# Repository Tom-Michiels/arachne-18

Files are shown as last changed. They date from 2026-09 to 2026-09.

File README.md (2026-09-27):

<div align="center">

# ARACHNE / 18 — v4

**Six legs. Eighteen servos. Three monolithic moving links per leg.**

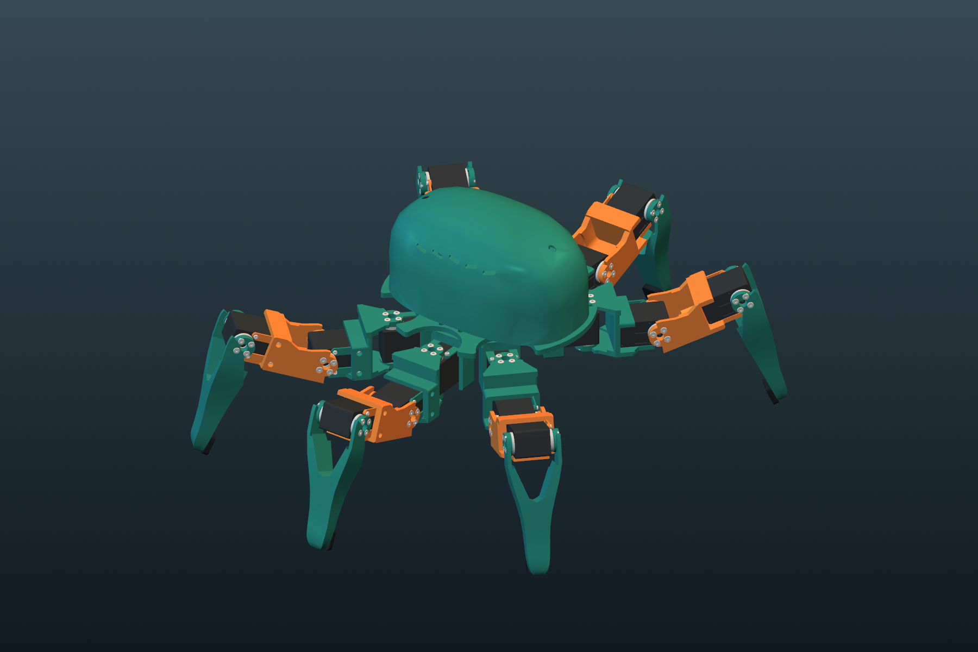
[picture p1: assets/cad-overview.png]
The complete v4 robot, rendered from its actual CAD


**18 × STS3215 12 V** · **3D printable** · **Onshape** · **MuJoCo + BAM**

[Onshape assembly](https://cad.onshape.com/documents/88edbeda4232642329938c14/w/19f5435855c2974f02fa7c68/e/916e6d95108202647e946643) · [Download print pack](print/ARACHNE_18_v4_print_pack.zip) · [Build guide](docs/build-guide.md) · [Simulation setup](docs/another-computer.md)

</div>

ARACHNE 18 is a compact six-legged prototype built around the owner's eighteen Feetech STS3215 12 V servos. This revision integrates the v4 leg and chassis into the complete robot: a single printed chassis, six identical leg modules, a removable controller carrier, and an organic ventilated canopy.

Each moving link is one printed piece. The tibia is symmetric, the horn cheeks have equal spacing, and the case cradles use the servo's factory mounting points. Local openings on the dummy side provide connector access. Horns sit inside the forks; recessed DIN 7380 button-head screws sit outside. There are no loose structural shims.

| Specification | v4 |
|---|---|
| Mechanism | Six yaw–hip–knee chains; 18 revolute joints |
| Chassis | 194 × 173.5 × 56 mm; six mounts on an 86 mm radius |
| Link geometry | Coxa 62 mm; hip offset −6.95 mm; femur 78 mm |
| Measured horn span | 36.5 mm; driven horn 2.5 mm, dummy horn 2.0 mm |
| Forks | 36.9 mm internal span; 5.5 mm cheeks; Ø7.3 mm center access |
| Battery envelope | 115 × 40 × 35 mm, excluding protruding plugs |
| Controller envelope | 90 × 60 × 18 mm; configurable 64 × 48 mm hole pattern |
| Printed parts | 8 unique files; 31 pieces including 6 TPU shoes and 4 PCB standoffs |
| Modelled hardware | 160 DIN 7380 M3 screws, 72 supplied PA2 case screws, 16 M3 inserts, 36 horns |
| Simulation | 19 rigid links, 18 actuators, 336 visual parts; estimated mass 2.333 kg |

## Inside the robot

| Removable electronics carrier | Symmetric six-leg layout |
|---|---|
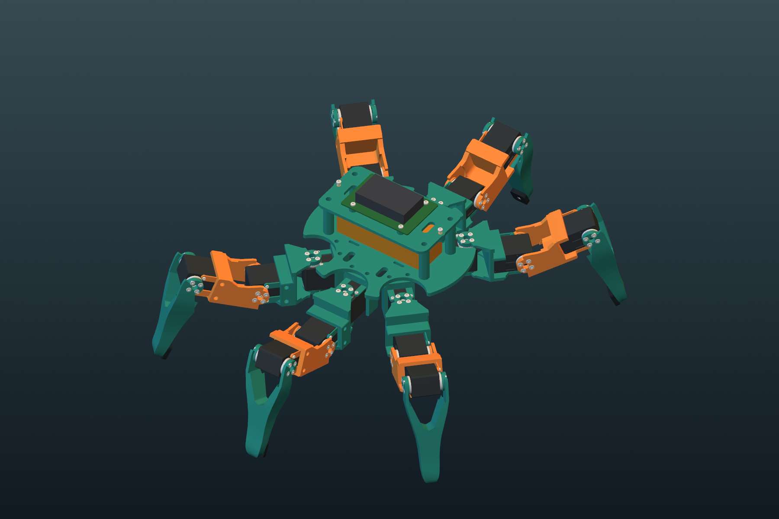
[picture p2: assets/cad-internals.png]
Actual v4 CAD with canopy removed
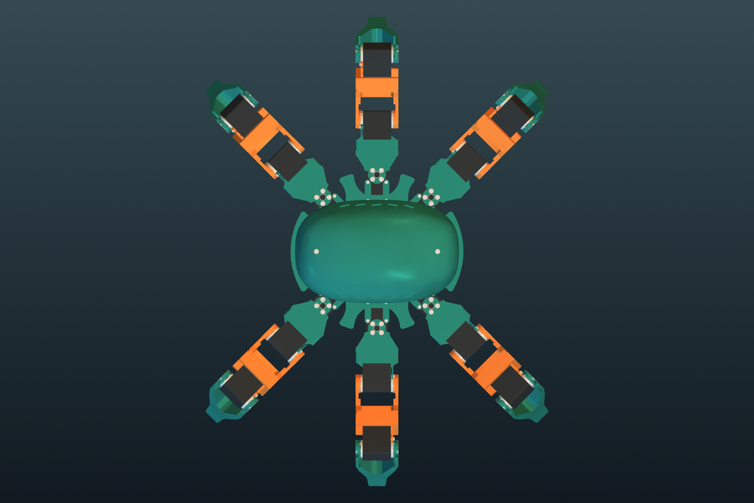
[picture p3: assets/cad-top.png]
Actual v4 CAD, top view
|  |  |

The battery rests on the chassis and is retained by two straps. Four integrated posts support the controller carrier. Its mounting screws are reached through deep open wells. Two recessed M3 screws hold the canopy; straight tool openings make them accessible from above. Four small standoffs provide a 6 mm PCB air gap.

The front and rear pairs can touch their toes through a checked coordinated pose: inward yaw approximately 57.51°, hip −20°, knee 0°. This is a reach pose, not a walking command. Independent joint limits do not guarantee arbitrary combinations are collision-free.

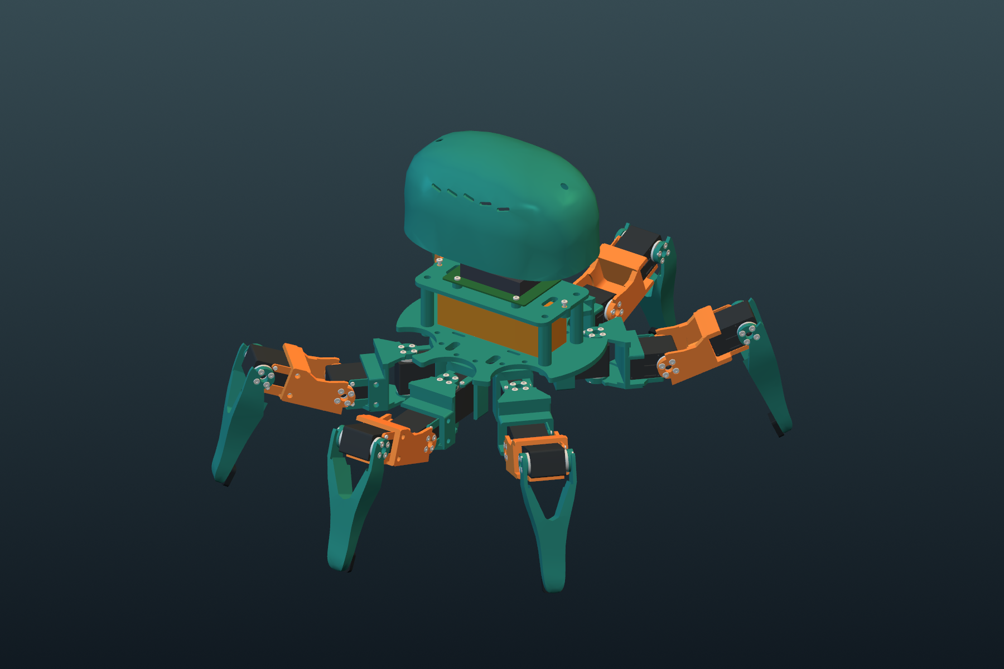
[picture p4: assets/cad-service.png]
V4 service view


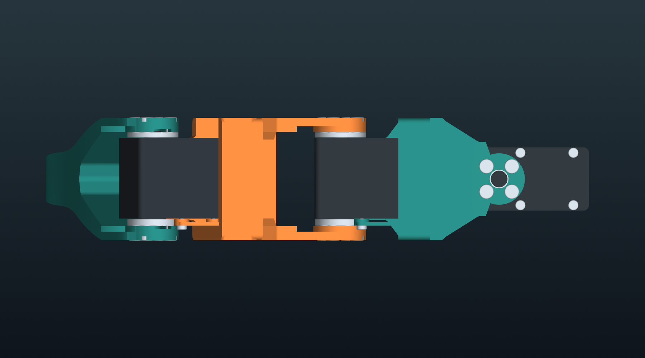
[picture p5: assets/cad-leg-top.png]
Top view of one v4 leg, with equal fork spacing


## Print and assemble

Download the [STL bundle](print/ARACHNE_18_v4_print_pack.zip), [assembled STEP](cad/ARACHNE_18_assembly.step), or [individual STEP parts](cad/parts). STL units are millimetres; use 100% scale and the supplied orientations. All parts fit the H2D.

Start with one complete leg and a real servo. The [build guide](docs/build-guide.md) explains mounting order, screw lengths, insert positions, connector clearance and support removal. M3 plastic-thread joints use **Ruthex RX-M3x5.7**, with **Ø4.0 × 7 mm pilots**. Horn screws thread into metal horns; supplied case screws thread into the servo's factory mounting points.

The structural pieces have continuous flat bed faces. The curved canopy needs internal support; support is also needed locally beneath some fork bridges. All eight parts were sliced successfully with an A1 geometry proxy profile. **Reslice for your H2D**; no machine-ready G-code is supplied.

## Run MuJoCo

From a fresh clone, with Python 3.12:

```sh
git clone https://github.com/Tom-Michiels/arachne-18.git
cd arachne-18
python3.12 -m venv .venv
source .venv/bin/activate
python -m pip install -r simulation/requirements.txt
python simulation/simulate.py --headless --seconds 10 --voltage 11.1
python simulation/validate.py
```

For an interactive viewer on macOS:

```sh
mjpython simulation/grounded_demo.py --seconds 300
```

Use `python` for the viewer on Linux/Windows. On Windows activate with `.venv\Scripts\activate`. See [setup on another computer](docs/another-computer.md) and the [simulation guide](docs/simulation.md).

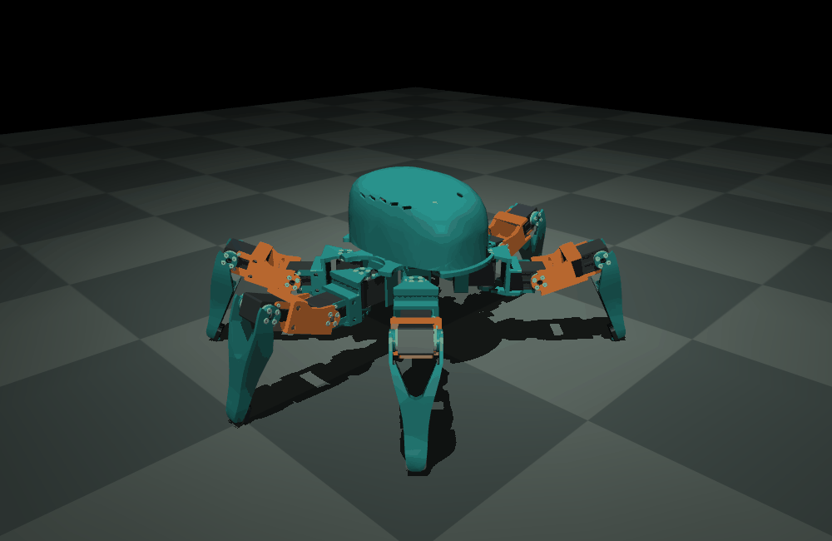
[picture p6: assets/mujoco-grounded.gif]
Actual v4 floating-base MuJoCo body-height exercise


The animation is a BAM-driven body-height exercise. All six feet remain in contact; the base is free. The 12 V actuator parameters are an explicitly labelled approximation derived from BAM's identified 7.4 V model and manufacturer operating points. [BAM assumptions](docs/bam-model.md).

## Existing RL work

**No RL retraining was performed for v4.** Existing checkpoints, measurements and walking/jump/terrain videos are preserved. They were produced with earlier geometry and do not establish v4 performance. The training model and inverse kinematics now use v4 dimensions; controller and geometry compatibility tests are included.

[Training documentation](training/README.md) · [Archived locomotion videos](https://tom-michiels.github.io/arachne-18/) · [Revision notes](docs/revision-v4.md)

## Validation and limitations

Eight valid single-solid print parts and eight watertight single-component STLs pass the current checks. The release includes screw/print clearance checks, driver access checks, the isolated leg's factory-hole and connector tests, chassis installation tests, sampled dorsal motion and paired-toe reach evidence. MuJoCo passes topology, joint axes, standing at three voltages, reset reproducibility and grounded motion checks. [Scope and reports](docs/validation.md).

This is a digitally checked prototype. Real servo/horn/plug fit, print tolerances, insert pull-out strength, fatigue and payload capacity need a physical one-leg trial. The controller and battery are envelopes because exact models have not been specified. Servo visuals are simplified exterior references; the original vendor STEP is retained for mechanical checks.

## Files and sources

| Folder | Contents |
|---|---|
| [cad](cad) | Assembly, unique-part layout, individual STEP solids, dimensions and reference geometry |
| [print](print) | Oriented STLs, print quantities and downloadable print pack |
| [simulation](simulation) | MJCF, local-frame meshes, BAM parameters, runtime and validation |
| [src](src) | Parametric CadQuery source, exporters, CAD checks and Onshape mate tooling |
| [docs](docs) | English build, simulation, validation and development guides |
| [training](training) | Updated model adapter and preserved historical RL work |

Actuator modelling uses [Rhoban/BAM](https://github.com/Rhoban/bam); simulation uses [MuJoCo](https://github.com/google-deepmind/mujoco). See [third-party notices](THIRD_PARTY_NOTICES.md). No project-wide open-source license has been selected; bundled BAM material retains its Apache-2.0 license.

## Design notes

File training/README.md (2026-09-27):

# Smooth, IMU-aware locomotion

> **Mechanical revision v4:** checkpoints, recorded metrics and videos below are historical pre-v4 results. No RL retraining was performed. Current model/IK adapters use v4 geometry; prior performance is not established for v4. See [revision notes](../docs/revision-v4.md).

**Latest:** [faster walking with longer strides](LONG_STRIDE.md), including
a 44-second video and 26/26 reference checks. The new forward gait reaches
22.4 cm/s with 43% greater foot excursion than the original solo gait.
The [uneven-ground curriculum](TERRAIN.md) has passed admission through
4 mm obstacles and stops before the unmastered 8 mm stage.

ARACHNE now has a learned command-conditioned walking policy, independent BAM
validation, and real physics recordings. Start with
[`policies/omni.json`](policies/omni.json): it walks forward, backward, sideways,
diagonally, turns both ways, combines translation and rotation, and stops.

This is **episodic reward-based policy search using the cross-entropy method
(CEM)** over a 12-parameter controller. It is not a trained neural network or
PPO. The tripod pattern and inverse kinematics are explicit priors; training
learns cadence, stance fraction, foot clearance, stride/yaw/lateral gains,
body height, stance radius, IMU feedback strength, and phase corrections.

## Recorded results before the symmetric-leg revision

These archived verification figures used the original collision proxies and
the complete BAM M6 runtime at a 1 ms physics step. The symmetric-leg CAD
revision subsequently updated `simulation/arachne.xml`. Gait, terrain and jump
unit tests pass with the revised model, and the general walking policy passed
a five-second BAM smoke run; the full performance table below has not yet been
remeasured on that geometry. Training used a separate approximate model.

| Case | Measured motion | Body tilt RMS | Height variation, standard deviation |
|---|---:|---:|---:|
| General policy, 14 cm/s forward command | 13.29 cm/s | 0.060° | 0.395 mm |
| General policy, 20 cm/s forward command | 19.3 cm/s | 0.064° | See validation JSON |
| Fast policy, 20 cm/s forward command | 18.98 cm/s | 0.068° | 0.431 mm |
| Continuous 40-second direction/turn/stop demo | Multiple commands | 0.084° | 0.376 mm |

The fast policy trades a small amount of speed for less foot slip: 2.36 cm/s
RMS versus approximately 3.7 cm/s for the general policy at the 20 cm/s command.
Use the general policy for arbitrary directions; the fast policy was optimized
and verified for forward motion only.

**26/26 held-out/reference checks passed**, including 16 directions (eight
intermediate directions were not in the training command set), both yaw signs,
a combined command, slow/fast movement, standing, friction 0.5/1.1, a 200 g
payload, and 0.25° orientation-estimate noise with 0.005 rad/s gyro noise. Each
case lasts 12 seconds. The 40-second continuous demo has no falls, no non-foot
ground contacts, no solver warnings, and a maximum tilt of 0.297°.

Reports: [`results/validation.json`](results/validation.json),
[`results/fast_bam.json`](results/fast_bam.json),
[`../assets/arachne-learned-omni.json`](../assets/arachne-learned-omni.json).
These are simulation results, with the repository's provisional 12 V BAM
approximation. A separate [uneven-ground curriculum](TERRAIN.md) now has bounded
simulation checks. Hardware, impacts, thermal limits and measured actuator
parameters have not been validated by this work.

## Why the movement is smooth

- Alternating support tripods have coordinated phases. The stance/swing
  horizontal paths join with continuous position, velocity and acceleration;
  the `sin^4` foot lift also has zero velocity and acceleration at touchdown.
- A five-degree polynomial ramps motion in; a 250 ms command filter blends
  changes of direction. Cadence and foot clearance decrease at lower speeds.
- Joint targets pass through a low-pass filter and a 4.717 rad/s slew limit,
  then stay inside the original ±20° yaw and ±15° hip/knee limits.
- IMU projected gravity controls body tilt. A short prediction using body-frame
  gyro adds damping. The controller never observes global position, absolute
  heading or simulator ground-truth linear velocity. Ground-truth velocity is
  used only by the training reward and evaluation metrics.

The original policy uses this running reward:

```text
+ 5.0 exp(-||v_xy - command_xy||² / 0.0016)
+ 1.5 exp(-(yaw_rate - command_yaw)² / 0.09)
- 90 tilt_xy²
- 20 ||roll_pitch_rate||²
- 80 vertical_velocity²
- 400 (body_height - 0.095)²
- 15 stance_foot_slip²
- 0.025 mean(target_rate²)
- 0.00015 mean(target_acceleration²)
- 0.025 mean(motor_torque²)
- 30 for a fall, excessive tilt/height or non-finite state
```

Search maximizes average return after a 1.5 s settling period. Omnidirectional
selection uses 70% mean command return plus 30% worst command return. The top
eighth of the population updates the sampling distribution, with variance
floors and a retained incumbent. There is no bonus for arbitrary speed, so
overshooting or standing still cannot replace command tracking.

The newer longer-stride experiment adds measured progress per cycle (capped
at 0.12 m), stronger slip penalties, and a target-jerk penalty. Its exact
weights and run configuration are stored alongside the results. The original
policy and its validation report remain available for comparison.

## Run the trained controller or render the videos

Python 3.12, from the repository root, in a separate environment:

```sh
python3.12 -m venv .venv-walk
source .venv-walk/bin/activate
python -m pip install -r training/requirements.txt
python training/test_gait.py
python training/evaluate.py --policy training/policies/omni.json --command .14 0 0
python training/validate_policy.py --policy training/policies/omni.json
python training/render_demo.py --policy training/policies/omni.json
python training/evaluate.py --policy training/policies/fast.json --command .20 0 0 --seconds 12
python training/render_army.py --run training/recordings/army
```

Evaluation, tests, and rendering need standard MuJoCo and BAM; they do not need
the custom Metal physics library. The HUD is telemetry over a real simulation
capture. macOS rendering needs a graphics-capable session.

## Train with the fast local simulator

Training requires the **fused** `_mjmlx_native` build of MuJoCo-MLX-Cpp. This run
used the existing local `metal-opt` branch, commit
`4d84f84871f59378fa9f5636cf40efe16ed3f321`, on an Apple M4 Max. At publication time
that local fused implementation is not on the public upstream `main` branch;
cloning public main alone does not provide this training backend. The scripts
check support and fail explicitly if the necessary fused API/model support is
missing. Point `PYTHONPATH` to the local build with a matching Python/MLX ABI.

```sh
export PYTHONPATH=/path/to/MuJoCo-MLX-Cpp/build
python training/build_model.py
python training/check_metal.py

# First train and independently verify forward walking.
python training/metal_search.py --population 256 --generations 30 --speed .14 --out training/runs/forward
python training/evaluate.py --policy training/runs/forward/policy.json --command .14 0 0

# Then train eight directions, turns, a curve, and standing together.
python training/metal_search.py --stage omni --population 128 --generations 30 --speed .14 \
  --resume training/runs/forward/policy.json --out training/runs/omni
python training/validate_policy.py --policy training/runs/omni/policy.json

# Optional faster forward policy, preserving the smoothness objective.
python training/metal_search.py --population 256 --generations 25 --speed .20 \
  --resume training/runs/omni/policy.json --out training/runs/fast

# Record genuine population rollouts for the army video.
python training/metal_search.py --population 128 --generations 16 --seconds 8 --speed .14 \
  --capture-generations 0 5 15 --out training/runs/army
python training/render_army.py --run training/runs/army
```

The published weights came from an initial forward exploration, a second
forward smoothness pass, then the omni and fast stages. The current commands
use the final reward from the beginning and retrain a new run, not a bitwise
reproduction of the earlier exploration. Seeds, generation counts, returns,
timings and controller hash are in
[`results/training_summary.json`](results/training_summary.json).

The omni stage evaluated 1,536 environments per generation. It completed
27.648 million control steps / 138.24 million physics substeps in approximately
132 seconds, including logging and local background work. This is an observed
run timing, not an isolated benchmark.

## Model approximation and validation boundaries

`build_model.py` preserves CAD inertias, kinematics, mass and joint limits.
For the fused solver it uses Euler at 2 ms, pyramidal friction, 26-vertex foot
hulls and a torso hull. Training excludes self-collision and uses static
BAM-derived proportional gains, rotor inertia, damping/back-EMF and Coulomb
friction. It includes the external target filter, slew limit and 10 ms target
delay; the original reference adds BAM's approximately 5 ms command delay and
dynamic load-dependent friction. Foot slip during training uses a height-based
contact estimate; reference reports use actual ground contacts.

The independent 32-environment, five-substep comparison against MuJoCo C on the
same approximate model gave maximum errors of `9.04e-8` in qpos and `2.51e-6`
in qvel. This tests the backend for those states; it does not make the approximate
model identical to the full BAM model. Final policy validation and all solo
video physics use the original model and complete BAM runtime.

## Training-army provenance

The army video shows **128 independent candidates**, not copies of one trained
animation. The three clips replay actual qpos tensors recorded during
generations 0, 5 and 15 of a new training run (displayed as generations 1, 6 and
16). Original structural CAD meshes are positioned from those tensors in a
MuJoCo renderer. Small hardware is omitted in the distant overview.

Grid placement is a display offset: the training worlds do not collide with
one another. Gold shells mark the elite candidates selected from the completed
generation. Playback is at simulation time; the title does not claim rendering
ran live at training speed. Raw recordings include candidate parameters,
commands, rewards and metrics in [`recordings/army/`](recordings/army/), with
SHA-256 hashes in the [video manifest](../assets/arachne-training-army.json).

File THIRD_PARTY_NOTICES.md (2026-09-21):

# Sources and third-party notices

## Better Actuator Models

[BAM](https://github.com/Rhoban/bam) is developed by Rhoban and distributed under Apache-2.0. This repository includes an original STS3215 7.4 V M6 parameter snapshot and a modified 12 V approximation. The modification fits effective torque/speed coefficients to Feetech's 12 V datasheet; it is not an upstream identified 12 V model. See [the model notes](docs/bam-model.md) and the [included license](licenses/BAM_APACHE_2.0.txt).

Upstream parameter snapshot: `e9a619d56da5236206f4de6ceec2c1ee1b497b5c`. Installed runtime: `better-actuator-models==1.0.2` from PyPI.

## Mechanical and electrical references

- [Feetech ST-3215-C018 12 V specification](https://cdn.robotshop.com/media/F/Fit/RB-Fit-155/pdf/feetech_12v_30kg_cm_magnetic_encoding_servo_sts321_specification_pdf.pdf): torque, speed, voltage and current. Revision A/0, 20 July 2023, pages 3–4.
- [Feetech STS3215 translated drawing](https://core-electronics.com.au/attachments/uploads/sts3215-smart-servo-datasheet-translated.pdf): common case and both horn interfaces, pages 6–7. Check the actual supplied hardware before printing the full set.
- [Waveshare ST3215](https://www.waveshare.com/wiki/ST3215_Servo): TTL interface and 3S/12.6 V compatibility.
- [Norelem EN ISO 7380-1 button-head screws](https://www.norelemusa.com/en-us/Product-Overview/Flexible-standard-component-system/07000/Nuts-screws-washers-securing-elements/Button-head-screws-EN-ISO-7380/Hexag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): M3 head diameter 5.7 mm, height 1.65 mm and 2 mm hex socket.

Vendor documents are linked rather than redistributed. The servo, horn, controller and battery solids are simplified project references, not official manufacturer CAD.

## Tools

- [MuJoCo](https://github.com/google-deepmind/mujoco) and [modeling documentation](https://mujoco.readthedocs.io/en/stable/modeling.html).
- [CadQuery](https://github.com/CadQuery/cadquery) for construction and STEP export.
- [Onshape assembly API](https://onshape-public.github.io/docs/api-adv/assemblies/) for native mating.

These products and their trademarks belong to their respective owners. Their use does not imply endorsement. Runtime dependencies retain their own licenses.

## Project and artwork

No project-wide license has been selected by the owner. Inclusion on GitHub is not itself an open-source license grant. The BAM material retains the separate license above. Image provenance and the generation prompts are documented in [media.md](docs/media.md).

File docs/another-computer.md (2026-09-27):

# Start on another computer

Clone the public repository; all current model assets are ordinary Git files:

```sh
git clone https://github.com/Tom-Michiels/arachne-18.git
cd arachne-18
python3.12 -m venv .venv
source .venv/bin/activate
python -m pip install -r simulation/requirements.txt
python simulation/validate.py
python simulation/grounded_demo.py --headless --seconds 10
```

Windows activation: `.venv\Scripts\activate`. Interactive viewer: `mjpython simulation/grounded_demo.py` on macOS, `python simulation/grounded_demo.py` on Linux/Windows. Use `git pull --ff-only` to retrieve subsequent updates. Onshape credentials and CadQuery are unnecessary for simulation.

The current robot is **mechanical revision v4**. Existing RL checkpoints, results and videos are from earlier geometry. They are preserved, but have not been retrained or performance-validated for v4.

## Prepare training

The CPU MuJoCo/BAM runner works without a GPU. A custom training environment can wrap `simulation/simulate.py`'s `Robot` class: reset with `robot.reset()`, send 18 relative joint-angle targets in `joint_map.json` order, and call `robot.step(target)` once per millisecond. Observations can use joint positions/velocities via the controller indexes, body pose/velocity, IMU readings and contacts. Define rewards, action scaling, terrain and termination in your environment.

For the repository's existing training utilities:

```sh
python -m pip install -r training/requirements.txt
python training/build_model.py
python -m unittest discover -s training -p 'test_*.py'
```

The fast Apple Metal training route additionally requires the external MuJoCo-MLX-Cpp native extension described in [training/README.md](../training/README.md). That route is specific to supported Apple hardware. The CPU BAM model is not automatically an MJX/JAX model; another backend needs its own actuator integration.

Review [joint conventions and model assumptions](simulation.md) before starting new training. No training jobs are started by the setup commands above.

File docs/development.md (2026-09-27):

# Regenerating the v4 robot

Editable geometry lives in `src/v4_leg.py`, `v4_body.py`, `v4_dorsal.py`, `v4_hardware.py` and `v4_servo.py`. `build_v4.py` assembles them. The older entry point `build_cad.py` now calls the v4 builder. `cad/parameters.json` is an output summary; editing it alone does not rebuild geometry.

## CAD build

CadQuery 2.8 needs a compatible Python/OCP environment. A Linux Docker environment avoids native OCP compatibility issues:

```sh
docker build -t arachne-cad -f src/Dockerfile .
docker run --rm -v "$PWD:/workspace" -w /workspace arachne-cad python src/build_v4.py
docker run --rm -v "$PWD:/workspace" -w /workspace arachne-cad python src/check_v4.py
docker run --rm -v "$PWD:/workspace" -w /workspace arachne-cad python src/check_v4_leg.py cad/reference/ST3215.step
docker run --rm -v "$PWD:/workspace" -w /workspace arachne-cad python src/check_v4_body.py cad/reference/ST3215.step
docker run --rm -v "$PWD:/workspace" -w /workspace arachne-cad python src/check_v4_installation.py
```

Alternatively install `src/requirements-cad.txt` in a compatible Python 3.11 environment and run those Python commands directly. The build writes only into ignored `build/v4/`, including STEP, oriented STL and BREP instance cache. It does not commit, upload or overwrite the released print files.

`cad/reference/validated_v4/` freezes the earlier checked component solids. The equivalence check allows reuse of their fit evidence and catches accidental changes during whole-robot integration. If intentionally changing a baseline component, review and rerun its fit/motion checks before explicitly updating that baseline; do not silently weaken the comparison.

## Export and validate simulation

From the CAD environment:

```sh
python src/export_v4.py
python src/render_gallery.py
```

This writes the current `simulation/` geometry, meshes, mass properties and joint map. It preserves BAM parameters and runtime code. STLs in `simulation/meshes/` use **metres and link-local coordinates**; printable STLs use **millimetres and bed orientation**. Never exchange them.

In the Python 3.12 simulation environment:

```sh
python simulation/validate.py
python simulation/grounded_demo.py --headless --seconds 8 --report simulation/grounded_validation.json
python training/build_model.py
python -m unittest discover -s training -p 'test_*.py'
python src/render_simulation.py
```

Rendering additionally needs Pillow and a usable OpenGL backend. No training job runs in these commands. Keep collision descriptions, mass assumptions and joint geometry synchronized when editing the design.

## Slice and publish locally

`src/audit_slicer_v4.py` invokes the installed macOS Bambu Studio CLI. It resolves profile inheritance and uses an A1 0.4 mm profile as a geometry proxy, because the CLI build does not expose a usable H2D profile. The supplied `v4_slicer_profile.json` is the audit process configuration, not a machine-ready H2D project. Reslice the release files on H2D.

After all CAD reports and `build/v4/slicer_audit.json` exist:

```sh
python src/package_v4.py
```

This replaces the canonical `cad/` and `print/` generated files, copies reports and builds the print ZIP. It removes obsolete current-release print/mesh files. Review the diff before committing. Historical v3 reports are explicitly separated in `validation/legacy-v3/`.

## Onshape maintenance

Import the complete assembly STEP into the project document with **flatten assemblies** enabled, to create a positioned 336-part Part Studio. The [official import documentation](https://onshape-public.github.io/docs/api-adv/translation/) describes API upload options. The source Part Studio contains imported solids, not the CadQuery parametric feature tree.

`create_onshape_v4.py` creates/resumes a native assembly from the specified Part Studio and writes a new mate plan. It checks all names against the CAD instance list and fixes the chassis on insertion. It uses `build/onshape/v4_assembly.json` as its resume record; retain that record when resuming the same publication. Use a new build workspace for a different document/revision.

```sh
python src/create_onshape_v4.py --key-file /external/onshape-key.json --document DOCUMENT_ID --workspace WORKSPACE_ID --part-studio PART_STUDIO_ID
python src/onshape_mates.py --key-file /external/onshape-key.json
python src/update_onshape_limits.py --key-file /external/onshape-key.json --apply
python src/onshape_mates.py --key-file /external/onshape-key.json --stage verify
```

The native mate installer resumes by feature name and checks feature status. It creates explicit part-origin-based mate connectors, 317 fastened mates and 18 revolute mates. Each servo case belongs to the upstream rigid group; horns and horn screws belong to the downstream group. The limits and axes match the current joint map.

Keep API credentials in an external mode-0600 JSON with `accessKey` and `secretKey` fields. No credential is needed for local CAD, simulation or training. The committed mate plan contains public document/instance identifiers only. Never reuse its exact instance IDs for a different assembly without regenerating the plan.

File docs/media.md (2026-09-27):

# Media provenance

The README uses current v4 geometry throughout:

- `assets/cad-overview.png`, `cad-internals.png`, `cad-top.png`, `cad-service.png`, `cad-leg-top.png` and `cad-horn-detail.png` are VTK renders of the exported v4 CAD meshes. The service view raises the cover for visibility.
- `assets/mujoco-preview.png` and `mujoco-grounded.gif` are frames from the current floating-base MuJoCo/BAM body-height exercise. All six feet remain in support during the capture.
- Earlier `hero-workbench.png` and `hero-studio.png` are AI-assisted presentation artwork of earlier concepts. They are preserved as historical media, not current mechanical references.
- All existing learned walking, jumping, terrain and training-army videos are historical pre-v4 results. They were not regenerated or retrained for this release. The video page labels this distinction.

Rendering commands are in [development.md](development.md). Current CAD images are generated directly from geometry, without image-generation edits.

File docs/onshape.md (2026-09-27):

# Native Onshape v4 assembly

[Open ARACHNE 18 — v4 articulated assembly](https://cad.onshape.com/documents/88edbeda4232642329938c14/w/19f5435855c2974f02fa7c68/e/916e6d95108202647e946643)

[Open its source Part Studio](https://cad.onshape.com/documents/88edbeda4232642329938c14/w/19f5435855c2974f02fa7c68/e/d68fc9f6aee00c72d944de06)

The v4 assembly is a separate named tab in the existing project document. Earlier tabs preserve the preceding design. All 336 imported source parts are solid bodies, including the printed structure, 18 servo exterior references, 36 horns, 160 DIN 7380 M3 screws, 72 factory case screws, 16 inserts and the battery/controller references.

[Open the eight unique printable parts](https://cad.onshape.com/documents/88edbeda4232642329938c14/w/19f5435855c2974f02fa7c68/e/f85bc8278acffc5ff06239e0)

## Mate graph

The fixed chassis anchors 19 rigid groups. **317 fastened mates** attach each group's printed components, cases, horns, screws and inserts. **18 revolute mates** provide the six yaw–hip–knee chains. Servo cases belong to the upstream group; rotating horns and their screws belong to the downstream group.

```text
fixed chassis → yaw → coxa → hip → femur → knee → tibia + TPU shoe
```

`R_L1_yaw`, `R_L1_hip`, `R_L1_knee` and equivalents for L2–L6 identify the revolute mates. `F_` names are fastened mates; `MC_` and `J_` names are explicit mate connectors. All names are English.

Hip neutral is +20°, knee neutral is −85°. Joint values are offsets from that pose. Native limits use front/rear yaw 60° inward/35° outward, middle yaw ±35°, hip −50°/+25° and knee −20°/+100°. [Joint conventions](simulation.md).

The precise instance graph is in [onshape_mate_plan.json](../simulation/onshape_mate_plan.json). The [native readback report](../simulation/onshape_validation.json) checks instance/mate counts, solver feature status, fixed chassis and neutral transforms. The [limit report](../simulation/onshape_motion_validation.json) checks all 18 limit definitions. These API checks do not claim a separate interactive animation test. CAD and MuJoCo motion checks are documented independently.

## Editing and export

The STEP import preserves solids and placement, not CadQuery feature history. Change the parametric source in `src/v4_*.py` and regenerate when modifying geometry. The assembled servo references simplify the exterior; the original vendor STEP is retained locally for mechanical fit checks.

The MuJoCo model is generated from the same positioned CAD solids, rigid groups and joint frames. The floating base receives one global height adjustment to place the actual TPU shoes on the floor. See [development.md](development.md) for reproducible build and native mate commands.

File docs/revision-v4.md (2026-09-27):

# Complete mechanical revision v4

This release integrates the independently developed v4 leg and body into the complete six-leg robot.

- Three monolithic moving links per leg replace split cheek plates, clamps and structural joining hardware.
- Symmetric tibia and equal fork spacing; functional dummy-side cable and shaft-entry reliefs remain local.
- Factory servo case holes, recessed DIN 7380 horn screws and measured 36.5 mm horn span are retained.
- A one-piece scalloped chassis supports all six yaw servos and the battery straps.
- A removable carrier with integral posts, a configurable PCB mount and a ventilated organic canopy complete the dorsal compartment.
- Eight unique print files produce 31 printed pieces. The four small standoffs provide PCB electrical clearance; they are not leg shims.
- STEP, oriented STL, native Onshape mates, MJCF meshes, inertias, joint maps, contact geometry, print BOM and English documentation are updated together.
- The previous 50 mm coxa is now 62 mm; hip height is −6.95 mm and neutral hip angle is +20°. The training IK derives these values from the joint map.
- The former spherical foot-contact approximation is replaced by the v4 shoe's mesh hull in the full simulation, and a rotated thin box in the fast training model.

No RL training was repeated. Policies, results and recorded videos are unchanged. To reproduce earlier measurements with their earlier robot, check out Git commit `9a6ca7c` in a separate clone/worktree. Current policy compatibility tests do not establish current walking speed, jump height or terrain performance.

V4 remains a physical prototype candidate: no load rating, fatigue life, insert pull-out strength or hardware gait has been measured.

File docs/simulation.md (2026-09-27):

# Simulating v4

The canonical model is `simulation/arachne.xml`. It is a floating-base, 19-link robot with 18 hinges. The fixed-base model `arachne_fixed.xml` suspends the robot for joint sweeps; it is not used for the grounded animation.

## Setup and checks

Install Python 3.12 and `simulation/requirements.txt` in a virtual environment. No CAD software, Onshape access, API keys or Git LFS are needed to simulate the committed files.

```sh
python simulation/simulate.py --headless --seconds 10 --voltage 11.1
python simulation/validate.py
python simulation/grounded_demo.py --headless --seconds 10
```

For an interactive viewer use `mjpython simulation/grounded_demo.py --seconds 300` on macOS, or `python` on Linux/Windows. Run `python simulation/simulate.py --help` for standing and fixed-base sweep options. A window may need a working graphics driver; headless physics does not need a renderer.

## Joint convention

`joint_map.json` is authoritative. Servo IDs 1–18 follow `L1_yaw, L1_hip, L1_knee, L2_yaw, … L6_knee`. Coordinates use metres, kilograms, seconds and radians. +X is forward, +Z is up; the six leg roots lie at 45°, 90°, 135°, 225°, 270°, 315° around the body.

All joint positions are **offsets from the assembled neutral pose**, not absolute servo encoder values. Neutral hip angle is +20° and knee angle is −85°. Coxa length is 62 mm, hip vertical offset −6.95 mm, and femur length 78 mm. In `q=0`, all CAD and MuJoCo link frames coincide; link axes are aligned with the world axes. Pitch axes are the local negative Y direction, expressed in world coordinates.

| Joint | MuJoCo offset limits | Absolute mechanical angle |
|---|---|---|
| Front/rear yaw | 60° inward, 35° outward | Same as offset |
| Middle yaw | ±35° | Same as offset |
| Hip | −50° to +25° | −30° to +45° |
| Knee | −20° to +100° | −105° to +15° |

The front-pair toe-touch example has L1 yaw −57.50946°, L6 yaw +57.50946°, hip offset −40° and knee offset +85°. Rear uses L3 positive yaw and L4 negative yaw. The checked path linearly interpolates all three angles together from neutral over 13 samples. Keep the other legs neutral. Individual axis limits do not imply that every multi-leg combination is collision-free.

## Actuation and contacts

`simulate.Robot` runs BAM at a 1 ms timestep. `robot.step(target)` accepts 18 joint targets in radians, applies the approximate 12 V STS3215 firmware/motor/friction model and advances one physics tick. For a 50 Hz policy, hold the target for 20 ticks. Reset with `robot.reset()` so the firmware target and delay history reset too.

The `arachne.xml` actuators accept **torque**, not position. Loading the XML in MuJoCo without the Python controller bypasses BAM; sending joint angles straight to those actuators is incorrect.

Foot contacts use the convex hull of the actual TPU shoe meshes. A foot can generate multiple simultaneous contact points, so support checks count distinct feet rather than demanding exactly six points. The v4 grounded exercise produces 12 points on six feet in the tested run. The base is free and settles from 2 mm above the CAD sole plane.

Servo cases have box collision proxies, the canopy an ellipsoid proxy, and lower links simplified capsules. Printed visual meshes are not all used for self-collision. These approximations cannot certify CAD clearance; use the CAD reports for that. Cables, TPU compliance, backlash and structural flex are not modelled. Total estimated mass is 2.333 kg; substitute actual sliced/measured part and payload masses before hardware transfer.

The 12 V BAM approximation is retained unchanged from the prior release. See [actuator assumptions](bam-model.md).

## Training compatibility

`training/gait.py` now reads the v4 geometry from `joint_map.json`. `training/build_model.py` rebuilds the fast approximate training model with v4 inertias, limits and rotated shoe contact boxes. That model uses static BAM-derived coefficients and omits several effects of the full controller. Final policy evaluation should use `simulation/simulate.py`.

```sh
python training/build_model.py
python -m unittest discover -s training -p 'test_*.py'
```

These commands build and test; they do not train. All 17 geometry/controller/terrain tests passed for this release. Existing policy files and recorded results remain historical; no v4 locomotion performance has been established and no RL retraining was requested or performed. See [training history](../training/README.md).

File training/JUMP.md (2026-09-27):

# Maximum whole-robot jump clearance

> **Mechanical revision v4:** checkpoints, recorded metrics and videos below are historical pre-v4 results. No RL retraining was performed. Current model/IK adapters use v4 geometry; prior performance is not established for v4. See [revision notes](../docs/revision-v4.md).

[Watch the jump](https://tom-michiels.github.io/arachne-18/#jump).

Two separate single-jump policies are available:

- **[jump.json](policies/jump.json):** the highest clearance found in the standard
  1 ms MuJoCo/BAM model. At the recorded apex, the entire collision model clears
  the ground by **2.51 cm**. An independent check of every rendered CAD mesh
  vertex gives **2.40 cm** clearance for the lowest actual model part.
- **[jump_robust.json](policies/jump_robust.json):** selected for consistent
  clearance across 1, 0.5 and 0.25 ms physics timesteps: **2.08, 2.04 and 2.01 cm**
  respectively in the collision model.

These are the best candidates found in this finite search, not a proof of the
mechanism's absolute maximum. The walking policies remain separate.

## Objective

At each sample, compute the lowest world-space point of every robot collision
geometry, including all six feet, shins, motor housings and the body. Define
`clearance(t)` as the minimum of those heights above the ground plane.

The main reward is the maximum clearance sustained across three consecutive
10 ms samples, with no ground contact and at least 1 mm clearance throughout.
This gives a 20 ms persistence requirement and excludes the initial settling
period. A robot with one grounded foot cannot earn a positive jump reward.
**There is no upright, yaw, tilt or landing-posture reward.** Tilt is recorded
for diagnosis only. Before a candidate gets airborne, an upward-velocity shaping
term supplies a nonpositive search score; it cannot outrank a valid jump.

This metric measures clearance under the whole robot, not the change in body
height from its initial standing pose. The robot can improve it by pushing off
and retracting its legs. Original CAD joint ranges, gravity, robot masses and
BAM servo dynamics remain in place. Actuator targets use the existing 100 Hz
filter and rate limit.

## Controller and search

The timed policy waits 0.6 s in the neutral state, crouches, holds briefly,
pushes off, retracts the legs, holds the tuck and then blends back toward neutral.
Four learned durations and three learned yaw/hip/knee poses define the selected
13-parameter policy. Its JSON includes parameter names and control constants.
It uses elapsed time from the jump command; it assumes the neutral starting
state and does not use ideal simulator position or velocity as actor inputs.
It currently has no IMU feedback. Landing recovery has not been optimized.

CEM searched 20 generations of 128 symmetric candidates, then 18 generations
with independently parameterized legs and 18 further symmetric generations.
The asymmetric search did not beat the symmetric result. Coordinate refinement
improved the maximum-height candidate. A second refinement maximized the worst
sustained clearance across three physics timesteps, producing the robust policy.
This is learned parameter search over a motion prior, not a neural PPO policy.

## Reference checks

Peak collision-model clearance, in centimetres:

| Condition | Maximum-height policy | Robust policy |
|---|---:|---:|
| Standard 1 ms timestep | 2.51 | 2.08 |
| 0.5 ms timestep | 1.94 | 2.04 |
| 0.25 ms timestep | 1.84 | 2.01 |
| Friction 0.5, 1 ms | 2.02 | 1.92 |
| Friction 1.1, 1 ms | 1.91 | 1.86 |
| Additional 200 g, 1 ms | 1.57 | 2.14 |

All six conditions get the whole collision model airborne without solver
warnings. These are deterministic model checks, not a statistical hardware
success rate. Timestep sensitivity is substantial for the maximum-height policy;
use the robust variant when consistency across these numerical settings matters.
The numerical checks do not establish real-world actuator or landing performance.

The maximum-height recording has approximately 0.13 s of airborne samples,
3.82 rad/s maximum joint speed and 3.76 Nm maximum modeled motor torque. At the
clearance apex, body tilt happens to be only 0.20°; staying upright was not rewarded.

- [Maximum-height checks](results/jump_validation.json)
- [Robust-policy checks](results/jump_robust_validation.json)
- [Search settings and histories](results/jump_training.json)
- [Film metrics, CAD clearance audit and policy hash](../assets/arachne-jump.json)

## Use and reproduce

From the repository root, with the existing MuJoCo/BAM environment:

```sh
python training/test_jump.py
python training/check_jump.py
python training/check_jump.py --policy training/policies/jump_robust.json \
  --out training/results/jump_robust_validation.json
python training/render_jump.py
```

The film shows 3.5 seconds at real time, followed by a **labelled 4× slow replay**
of exactly the same state recording. The total video duration is 17.5 seconds.
The physics states and targets are saved in `assets/arachne-jump.npz` at 100 Hz.

For further search, copy checkpoints you want to keep: these commands write
`training/policies/jump.json` as they find candidates.

```sh
python training/jump.py --generations 20 --population 128 --std-floor .025
cp training/policies/jump.json training/runs/jump/symmetric.json
python training/jump.py --resume training/runs/jump/symmetric.json --asymmetric \
  --generations 18 --population 128 --out training/runs/jump-asymmetric
cp training/runs/jump/symmetric.json training/policies/jump.json
python training/refine_jump.py
```

`refine_jump.py` expects a 13-parameter symmetric checkpoint and refines against
all three timesteps. Select that checkpoint before invoking it after an
asymmetric search. `target(parameters, elapsed_seconds)` in `jump.py` provides
18 motor targets; apply the filter, delay and BAM dynamics shown in the evaluator.

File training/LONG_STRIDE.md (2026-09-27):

# Faster walking with longer strides

> **Mechanical revision v4:** checkpoints, recorded metrics and videos below are historical pre-v4 results. No RL retraining was performed. Current model/IK adapters use v4 geometry; prior performance is not established for v4. See [revision notes](../docs/revision-v4.md).

This report records the previous first film. The [latest forward gait](SPRINT.md)
reaches 29.9 cm/s with larger steps.

The `policies/long_stride.json` reaches **22.4 cm/s** in the original MuJoCo
model with full BAM M6 servo dynamics. Compared with the original 13.3 cm/s
solo gait, speed increases **68%**, actual foot excursion increases **43%**,
and cadence increases only **11%**. Original joint limits remain unchanged.

[Watch this earlier recording](../assets/arachne-long-stride.mp4).

## Measured comparison

Each reference case runs for 12 simulated seconds, with the first two seconds
excluded from steady-state averages. Foot excursion is the mean peak-to-peak
body-relative foot travel along the command direction across all six feet and
complete cycles. Body travel per cycle is measured speed divided by cadence;
slip is checked separately, so a long commanded trajectory alone is not evidence
of a longer useful stride.

| Metric | Original solo gait | Previous fast forward gait | New longer-stride gait |
|---|---:|---:|---:|
| Forward command | 0.14 m/s | 0.20 m/s | 0.26 m/s |
| Measured forward speed | 13.29 cm/s | 18.98 cm/s | 22.38 cm/s |
| Foot excursion | 3.42 cm | 4.33 cm | 4.90 cm |
| Body travel per cycle | 6.12 cm | 7.97 cm | 9.31 cm |
| Cadence | 2.17 Hz | 2.38 Hz | 2.40 Hz |
| Body tilt RMS | 0.060° | 0.068° | 0.105° |
| Body height standard deviation | 0.395 mm | 0.431 mm | 0.509 mm |
| Stance-foot slip RMS | 2.23 cm/s | 2.36 cm/s | 4.37 cm/s |
| Target jerk RMS | 1294 rad/s³ | 2028 rad/s³ | 2797 rad/s³ |

The faster gait has a measured smoothness tradeoff: slip and target jerk are
higher than in the gentle original gait. It stays within the declared faster
gait limits and keeps a steady body. The 68% comparison is against the original
solo gait, not against the previous 20 cm/s command test.

## Verification

**26/26 checks pass** for the final checkpoint: 16 translation headings at a
0.24 m/s command, 0.26 m/s straight ahead, slow movement, both turning signs,
a walking turn, standing, friction 0.5 and 1.1, a 200 g payload, and 0.25°
orientation-estimate noise with 0.005 rad/s gyro noise. Sideways and diagonal
measured speeds are lower than the forward maximum; see the per-case report.

The predeclared faster-gait bounds are velocity RMSE < 0.065 m/s, yaw-rate RMSE
< 0.12 rad/s, body tilt RMS < 0.75°, stance-foot slip RMS < 0.055 m/s, target
acceleration RMS < 60 rad/s², target jerk RMS < 3000 rad/s³ and actual maximum
joint speed < 4.8 rad/s, with no falls, non-foot ground contacts or warnings.
These bounds are distinct from the stricter, slower [terrain gates](TERRAIN.md).
Some cases are close to their limits, so this is a bounded simulation result,
not evidence of hardware robustness or unrestricted operating speed.

Several commands were used during checkpoint selection; the 26 checks are a
reference verification battery, not 26 entirely unseen learning tasks.

- [Final validation and policy hashes](results/long_stride_validation.json)
- [Checkpoint selection, including rejected candidates](results/stride_selection.json)
- [Training configuration, weights and return histories](results/long_stride_training.json)

## Training and selection

The fast fused MuJoCo/Metal simulator first searches forward motion and then
eight directions, turns, a curve and standing. Compared with the original
reward, slip weight increases from 15 to 80, target rate/acceleration costs
are multiplied by 1.5, target jerk receives weight `8e-8`, and measured
progress per cycle receives a bonus capped at 0.12 m. The stride term uses
actual progress, rather than the desired foot position.

The static training servo approximation did not transfer every motion cleanly
to BAM. Parallel reference-model CEM therefore refines the GPU proposal,
including opposite directions and low friction. Its reward gives yaw tracking
more weight and penalizes slip/jerk threshold violations. Final selection then
checks the saved CEM checkpoints and a small 27-point cadence/lift/stride grid
against hard reference gates. The highest training return alone did not choose
the published policy. The chosen checkpoint is from reference generation 2,
with cadence multiplied by 1.01 and stride gain by 0.96.

All of this remains a compact 12-parameter controller with a tripod and inverse
kinematics prior. It is CEM policy search plus a local parameter grid, not PPO
or a neural policy. The actor uses the same IMU-only body feedback as before.

## Reproduce

Use the [training setup](README.md) and the recorded run configs. Evaluation
and video rendering need only the standard MuJoCo/BAM dependencies:

```sh
python training/benchmark_speed.py --policy training/policies/long_stride.json --speed .24
python training/render_demo.py --policy training/policies/long_stride.json \
  --fast --out assets/arachne-long-stride.mp4
```

The training chain is recorded in `results/long_stride_training.json`.
After the GPU stages, the reference refinement and selection commands are:

```sh
python training/refine_bam.py --resume training/runs/long-stride-omni/policy.json \
  --out training/runs/bam-refinement
python training/refine_bam.py --resume training/runs/bam-refinement/policy.json \
  --robust --speed .24 --generations 8 --out training/runs/bam-robust
python training/select_stride.py --runs training/runs/bam-refinement \
  training/runs/bam-robust --local-grid
```

The 44-second continuous recording uses the selected checkpoint, a smooth
command filter and native simulation-time playback. It contains startup,
acceleration, sideways/backward/diagonal walking, turning and stopping.
Lighting changes affect rendering only. No frame retiming or robot animation
is used. Hardware performance still depends on identified servo dynamics,
mechanical tolerances and physical validation.

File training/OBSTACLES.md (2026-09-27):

# Stones, rocks and bending grass

> **Mechanical revision v4:** checkpoints, recorded metrics and videos below are historical pre-v4 results. No RL retraining was performed. Current model/IK adapters use v4 geometry; prior performance is not established for v4. See [revision notes](../docs/revision-v4.md).

Uneven terrain includes discrete obstacles as well as height variations. The
reference simulator now includes individual collision stones and passive,
bending grass tufts. [Watch the obstacle films](https://tom-michiels.github.io/arachne-18/#terrain-pebbles).

## Physical models

- **Stones:** individually placed, partly buried ellipsoids with random size,
  height, orientation and position. They are fixed to the ground in this first
  model; rolling or displaced stones are a later extension.
- **Grass:** seven capsule-shaped collision blades per tuft, mounted on two passive
  spring-and-damper hinges. Contact bends the tuft and the spring restores it.
  Tufts interact with the robot and ground, but not with each other.
  This is an uncalibrated mechanical proxy, not a botanical or soft-soil model.
- **Mixed obstacles:** both models in the same scene. Heights are actual metres;
  the videos do not exaggerate them. A clear spawn area prevents initial overlap.

The actor still receives IMU gravity and angular velocity, commands and gait
phase. It has no obstacle map or camera. This tests a gait's ability to tolerate
contact; it does not yet demonstrate visual route planning or deliberate
selection of individual footholds. The added objects run in reference MuJoCo
with full BAM servo dynamics. They are not represented by the experimental
Metal heightfield backend.

## Curriculum

[obstacle_curriculum.json](obstacle_curriculum.json) is a separate progression,
so the earlier heightfield results retain their original meaning:

| Stage | Physical obstacle | Command speed |
|---|---|---:|
| Flat admission | Original plane | 14 cm/s |
| Small pebbles | 4–8 mm protruding stones | 10 cm/s |
| Short grass | 18–30 mm stem lengths | 10 cm/s |
| Larger stones | 8–18 mm protruding stones | 10 cm/s |
| Stones and grass | 8–18 mm stones with 20–40 mm grass | 10 cm/s |
| Tall grass | 30–60 mm stems | 10 cm/s |
| Large rocks | 25–50 mm protruding rocks | 10 cm/s |

These are curriculum targets, not a claim that every stage is mastered.
Promotion uses two independent seed batches, intermediate headings, walking
turns, IMU noise and flat-ground retention after refinement. Training replays
25% flat-ground tasks. It rewards progress and tracking while penalizing tilt,
bouncing, slipping and abrupt motor motion. Failed promotion preserves the last
accepted policy. Future work on large rocks may need more expressive control,
contact sensing and perception rather than only a higher open-loop leg lift.

Encounter gates additionally require recorded foot–stone contact or vegetation
contact; walking through an empty patch cannot pass solely through forward
progress. Solid stone contact is included in support-foot slip and non-foot
collision checks. Flexible grass contact is tracked separately: brushing a
blade is not treated as striking the body against a rock. Grass joints are
excluded from robot motor-speed metrics, and grass tips do not redefine the
load-bearing ground-clearance reference.

## Dense grass update

The current grass film replaces the sparse initial example. Tuft spacing is
**3 cm instead of 16 cm**, and each tuft carries **seven blades instead of three**.
That increases nominal density from 117 to **7,778 collision blades per square
metre**, about **66 times** the initial density. The rendered patch contains
987 passive tufts and 6,909 physical blades. The grass stages now explicitly use
this density; omitted parameters still reproduce the original sparse scenes.

The forward film uses a bounded patch from x=0.30 to 1.30 m and y=−0.48 to 0.48 m,
with the existing spawn exclusion and radial boundary. This bounds the physics
cost without adding decorative, non-colliding filler. Curriculum scenes retain
the full surrounding field for multiple headings. Each tuft shares two passive
hinges across its seven blades.

All three dense forward layouts (seeds 701–703) pass their gates. The film's
seed 701 records 884 control steps with vegetation contact, versus 98 in the
old sparse film. It reaches 7.48 cm/s with 0.155° body-tilt RMS. Grass resistance
now measurably slows the robot. These tests are not full stage promotion.
[Dense-grass validation](results/dense_grass_validation.json).

## Initial sparse-scene results

The following measurements predate the density increase; the saved report
contains the original specifications.

The existing general controller was evaluated on three layouts per obstacle
class, using a 10 cm/s forward command for 12 seconds:

| Obstacle class | Passed examples | Result |
|---|---:|---|
| Small pebbles | 3/3 | 8.37–8.77 cm/s actual speed; 0.43–0.62° tilt RMS |
| Short grass | 3/3 | 9.11–9.15 cm/s actual speed; 0.06–0.08° tilt RMS |
| Larger stones | 0/3 | Tracking and clearance-rate limits exceeded |
| Stones and grass | 0/3 | Tracking and clearance-rate limits exceeded |

The pebble film and the earlier sparse grass film use seed 701 at simulation
time. They record 486 foot–stone and 98 vegetation contact steps respectively.
Both pass their gates. The current denser grass film is described above. These
forward examples are not equivalent to
full curriculum promotion. Larger obstacles remain unmastered; failed trials
are retained in the [assessment report](results/obstacle_admission.json).

The subsequent full admission check passes both flat batches. For small stones,
29/30 and 28/30 held-out cases pass; the second batch falls below the required
95%. Three cases exceed velocity-tracking limits. No stone-stage promotion is
claimed, and later stages were not attempted by that admission run.
[Full admission results](results/obstacle_curriculum_admission.json).

## Reproduce

```sh
python -m unittest discover -s training -p 'test_*.py'
python training/assess_obstacles.py  # current, denser curriculum specifications
python training/assess_dense_grass.py
python training/render_obstacles.py
python training/curriculum.py --config training/obstacle_curriculum.json \
  --assess-only --max-stage 6 --out training/runs/obstacle-admission
```

To refine a failing stage after admission checks, omit `--assess-only` and set
a training budget, for example `--generations 8 --population 24`. The curriculum
stops at the first stage that cannot be promoted. Tall grass and large rocks
are proposed later stages, not validated capabilities. Spring stiffness,
damping, stem geometry and terrain friction need measurements before this
proxy can predict performance in real grass.

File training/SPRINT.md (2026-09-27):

# Faster forward walking with larger steps

> **Mechanical revision v4:** checkpoints, recorded metrics and videos below are historical pre-v4 results. No RL retraining was performed. Current model/IK adapters use v4 geometry; prior performance is not established for v4. See [revision notes](../docs/revision-v4.md).

[Watch the first video](https://tom-michiels.github.io/arachne-18/#fast).

The new forward gait reaches **29.9 cm/s**, compared with **22.4 cm/s** in the
previous first film. Actual foot excursion increases from **4.90 to 6.45 cm**.
That is **34% more speed and 32% larger steps**, while cadence decreases 1.9%.
The 20-second film shows continuous acceleration, forward walking and stopping.
Playback follows simulation time; the video is not sped up.

## Reference measurements

Both policies use the original MuJoCo model, original joint limits and full BAM
servo dynamics. Each comparison runs for 12 seconds, excluding the first two
seconds from steady-state averages. Foot excursion measures body-relative
peak-to-peak travel along the command direction, averaged across all six feet
and complete cycles. It measures actual motion, not just commanded step length.

| Metric | Previous first film policy | New first film policy |
|---|---:|---:|
| Forward command | 0.26 m/s | 0.34 m/s |
| Measured forward speed | 22.38 cm/s | 29.88 cm/s |
| Actual foot excursion | 4.90 cm | 6.45 cm |
| Body travel per cycle | 9.31 cm | 12.67 cm |
| Cadence | 2.40 Hz | 2.36 Hz |
| Body tilt RMS | 0.105° | 0.212° |
| Body height standard deviation | 0.509 mm | 0.623 mm |
| Stance-foot slip RMS | 4.37 cm/s | 5.36 cm/s |
| Motor-target jerk RMS | 2797 rad/s³ | 2884 rad/s³ |

The higher speed increases slip and body motion slightly. It remains within the
existing faster-gait limits; those limits were not relaxed. In the actual film,
body tilt stays below **0.51°**, height standard deviation is **0.58 mm**, and
there are no falls, non-foot ground contacts or solver warnings. The complete
film, including its transitions, also passes the faster-gait gates.

## Foot trajectory and learning

The controller adds one optional parameter to the existing IMU-aware gait:
a blend between the original swing-height curve `sin(pi*u)^4` and the wider
curve `64*u^3*(1-u)^3`, where `u` runs from zero to one during swing. Both curves
join the stance phase with zero velocity and acceleration. The wider curve
lifts the foot earlier and lowers it later. The selected blend is 0.9895.
Horizontal foot trajectories, joint limits, command filtering and servo limits
remain unchanged. Existing 12-parameter policies retain their original output.

CEM searches cadence, step gain, lift, body height, phase offsets and feedback,
then the added foot-arc blend. The final search evaluates 160 candidates per
generation for 10 generations in parallel reference MuJoCo/BAM simulations.
Its reward combines measured speed and actual foot excursion, with squared
penalties for exceeding the existing tracking, tilt, slip, acceleration, jerk
and joint-speed gates. Final selection uses longer 12-second checks, including
payload and IMU noise. This is compact policy search with a gait prior, not PPO.

## Validation and operating range

**26/26 reference checks pass**: 16 translation headings at a **0.24 m/s command**,
one forward case at **0.34 m/s**, slow motion, both turning directions, a walking
turn, standing, and friction/payload/IMU perturbations at **0.24 m/s**. The
maximum forward speed is not a claim about every heading or surface.

Separate tests at the **0.34 m/s command** pass for the nominal surface, 200 g
payload and IMU noise. Friction 0.5 fails the unchanged slip limit; friction 1.1
fails the velocity-tracking limit. These failures are retained in the comparison
report. Use the lower command for broader operating conditions. The terrain
films continue to use the separate general policy. Hardware performance has
not been validated.

- [Full comparison and high-speed perturbations](results/sprint_comparison.json)
- [26-case reference validation](results/sprint_validation.json)
- [Search settings and generation summaries](results/sprint_training.json)
- [Recorded film metrics and policy hash](../assets/arachne-faster-stride.json)
- [Previous longer-stride report](LONG_STRIDE.md)

## Reproduce

Use the existing [MuJoCo/BAM setup](README.md), then:

```sh
python training/test_gait.py
python training/benchmark_speed.py --policy training/policies/sprint.json \
  --speed .24 --forward-speed .34 --out training/results/sprint_validation.json
python training/render_sprint.py
```

To reproduce the broad-lift search from its saved initial mean:

```sh
python training/train_sprint.py --resume training/policies/sprint_search_start.json \
  --command .34 --generations 10 --population 160 --out training/runs/sprint
```

The highest six-second search score is a candidate, not an automatically accepted
replacement: use the longer reference battery and perturbation checks before
selecting a new controller. The renderer also saves per-control-step states in
an adjacent `.npz` file, allowing the motion and timing to be inspected locally.

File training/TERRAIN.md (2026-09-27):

# Uneven-ground curriculum

> **Mechanical revision v4:** checkpoints, recorded metrics and videos below are historical pre-v4 results. No RL retraining was performed. Current model/IK adapters use v4 geometry; prior performance is not established for v4. See [revision notes](../docs/revision-v4.md).

Watch the [terrain films](https://tom-michiels.github.io/arachne-18/#terrain):
rolling ground up to 4 mm, slopes up to 2°, and 4 mm plateaus. Each is a
continuous 12-second original MuJoCo/BAM run, at real-time playback and true
terrain scale. Reproduce them with `python training/render_terrain.py`.

The curriculum admits only an already smooth flat-ground controller. It then
increases terrain difficulty while retaining velocity tracking, a steady body
and smooth motor targets. It uses the original MuJoCo model and full BAM M6
servo runtime in parallel CPU workers. The local fused Metal backend does not
support heightfields; terrain training does **not** silently flatten the ground.

## Current measured status

The original general policy (`policies/omni.json`) passed **318 admission
episodes** across the first five stages. Each episode lasts 10 seconds, uses
held-out headings and includes 0.15° orientation-estimate noise plus 0.005 rad/s
gyro noise. These are simulation checks, not hardware results.

| Stage | Terrain | Walking command | Admission result |
|---|---|---:|---|
| 0 | Flat ground, including pure turns and standing | 0.14 m/s | 78/78 passed |
| 1 | Smooth bumps, amplitude at most 2 mm | 0.10 m/s | 60/60 passed |
| 2 | Rolling ground, amplitude at most 4 mm | 0.10 m/s | 60/60 passed |
| 3 | Smooth slopes, sampled gradient bounded to 2° | 0.10 m/s | 60/60 passed |
| 4 | Raised 4 mm plateaus | 0.10 m/s | 60/60 passed |
| 5 | Raised 8 mm plateaus | 0.10 m/s | Not promoted |
| 6 | Bumps, slopes and plateaus combined | 0.10 m/s | Not reached |

At 8 mm, progress and velocity/yaw tracking failed, and some trials did not
reach enough uneven ground. A bounded three-generation CEM training attempt
also did not pass promotion. The runner kept the last admitted policy and
stopped; it did not relax the thresholds. This curriculum is executable and
partially validated, not a claim of mastered arbitrary rough terrain.

The faster, longer-stride flat-ground policy is a separate checkpoint. Terrain
admission deliberately starts from the gentler general policy; high speed is
not assumed to transfer to obstacles.

Raw results: [admission](results/terrain_admission.json) and
[three-generation training attempt](results/terrain_training.json).

## Promotion and retention

`terrain_curriculum.json` defines all stages and thresholds. Promotion requires
two consecutive batches on fresh terrain seeds, each with at least 95% of
episodes passing every gate. No falling or solver-warning episode can be
hidden by that aggregate percentage. Each rough-ground batch combines three
seeds with eight held-out translation directions and two walking turns. Pure
turns and standing are also checked on flat ground. Turning in place after
walking onto an obstacle is a useful future extension, not covered by this
first battery.

Gates include:

- At least 70% and at most 125% of requested forward progress; linear velocity
  RMSE below 0.045 m/s and yaw-rate RMSE below 0.12 rad/s.
- Stage-specific body-tilt and terrain-relative clearance variability limits;
  at least 60 mm base-frame clearance, no non-foot ground contacts or warnings.
- Stance-foot slip RMS at most 0.050 m/s, target-rate RMS at most 1.8 rad/s,
  target-acceleration RMS at most 55 rad/s², and target-jerk RMS at most
  1600 rad/s³. Actual maximum joint speed stays below 4.8 rad/s.
- At least 25% of measured samples outside the flat spawn/entry area. Waiting
  near the start cannot pass an obstacle stage.

Training evaluates three terrain tasks and one flat replay task per candidate.
The reward balances command tracking against slip, tilt, body angular rates,
terrain-relative vertical motion, and motor-target rate, acceleration and
jerk. Selection combines 70% mean return with 30% worst-case return. Every
candidate that passes a new stage must also pass the complete flat battery
before promotion. `last_promoted.json` is only replaced after those checks.

## Terrain and observation contract

Seeded heightfields cover 4 × 4 m at 10 mm grid spacing. A 0.32 m radius flat
spawn disk blends smoothly into the ground by 0.54 m. Plateaus have one-cell
edges, not perfectly vertical stair risers. The terrain report records actual
height extrema. Dimensions remain in metres; the original robot mass, joints,
collision proxies and mechanical limits are retained.

The policy receives IMU projected gravity and gyro, a velocity command and
oscillator phase. It does not receive a height map, future footholds or perfect
linear velocity. Ground rays are exclusively for reward and evaluation, and
ray/grid agreement is regression-tested against MuJoCo's collision geometry.

## Run it

Use the [standard training dependencies](requirements.txt); no custom GPU
backend is needed. From the repository root:

```sh
python -m unittest discover -s training -p 'test_*.py' -v

# Assess admission, stopping at the first unmet stage.
python training/curriculum.py --assess-only --workers 8 \
  --out training/runs/terrain-admission

# Reproduce the bounded three-generation attempt at the 8 mm stage.
python training/curriculum.py --workers 8 --population 16 --generations 3 \
  --max-stage 5 --out training/runs/terrain-trained

# A larger training budget. It still cannot bypass any promotion gate.
python training/curriculum.py --workers 8 --population 24 --generations 8 \
  --out training/runs/terrain
```

For subsequent work, increase the training budget and test touch-down timing,
clearance and IMU feedback within the existing joint limits. Once 8 mm and
mixed ground pass, add walk-to-turn transitions on obstacles, friction and
payload randomization, then gradually increase speed while keeping the same
smoothness gates. Hardware terrain trials require identified actuator dynamics
and a separate physical validation process.

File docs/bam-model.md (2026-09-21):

# STS3215 12 V: provisional BAM M6 model

The upstream BAM project provides an identified **STS3215 7.4 V** model. This project uses a separately labeled **12 V approximation**, authorized for this prototype. It is not an identification of the user's 12 V hardware.

## Provenance

The original M6 parameter file is preserved as `simulation/bam_sts3215_7p4v_m6_original.json`, from [Rhoban/BAM](https://github.com/Rhoban/bam), commit `e9a619d56da5236206f4de6ceec2c1ee1b497b5c`. Its SHA-256 is `74d5068bd4453046fd5e33a11bfcc69a7f121740409f6818706a789b000df5e9`. Runtime dependency: PyPI `better-actuator-models==1.0.2`.

The parameter source snapshot and PyPI release do not expose exactly the same runtime API. This project's runner explicitly initializes the Feetech firmware target-smoothing state on reset, because the installed release normally initializes it when loading a measurement log.

## What was fitted

The official Feetech ST-3215-C018 12 V datasheet specifies **30 kg·cm (2.941995 Nm) stall output torque** and **0.222 s/60° no-load speed** at 12 V. `fit_bam_12v.py` solves for effective `kt` and `R` so the M6 net output matches those points with inherited friction.

| Parameter | Approximation |
|---|---:|
| Supply voltage | 12 V; runtime can override it |
| Effective motor constant `kt` | 2.3572085648 |
| Effective resistance `R` | 6.2986515716 |
| Firmware speed limit | 4.7171060865 rad/s |
| Net stall output after modeled friction | 2.941995 Nm |
| PWM limit | 0.97, inherited |

The M6 friction parameters, apparent rotor inertia, proportional-control scale and approximately 4.98 ms command delay are inherited from the 7.4 V identification. The original test-rig angle offset is set to zero. The runner interpolates delayed target history at the 1 ms simulation timestep. Voltage sag is disabled.

Reproduce the fit:

```sh
python simulation/fit_bam_12v.py
python simulation/validate.py
```

The output files are `bam_sts3215_12v_approx_m6.json` and `bam_12v_fit_report.json`. This modifies the tracked parameter/report files; inspect the diff before committing.

## Interpretation and limits

`kt` and `R` are **effective model coefficients**, not measured electrical properties. The datasheet's terminal resistance and current figures do not produce a consistent ideal DC motor model when combined directly with every torque/speed figure; this fit therefore targets the two mechanical points explicitly.

Do not use the model's inferred electrical current for wire sizing, pack sizing or battery-life estimates. The datasheet separately specifies 2.7 A stall current per servo. Thermal behavior, voltage sag, gearbox backlash and overload shutdown are not modeled reliably. Stall output torque is not a continuous load rating.

The 12 V approximation needs measured data before it can support quantitative hardware predictions. A useful next step is an actual BAM identification on the 12 V servos with the intended supply, firmware settings and load. Use `--parameters` to load a replacement model.

Sources: [BAM actuator catalogue](https://bam.readthedocs.io/en/latest/usage/actuators.html), [BAM MuJoCo integration](https://bam.readthedocs.io/en/latest/usage/mujoco_cpu.html), [Feetech 12 V datasheet](https://cdn.robotshop.com/media/F/Fit/RB-Fit-155/pdf/feetech_12v_30kg_cm_magnetic_encoding_servo_sts321_specification_pdf.pdf).

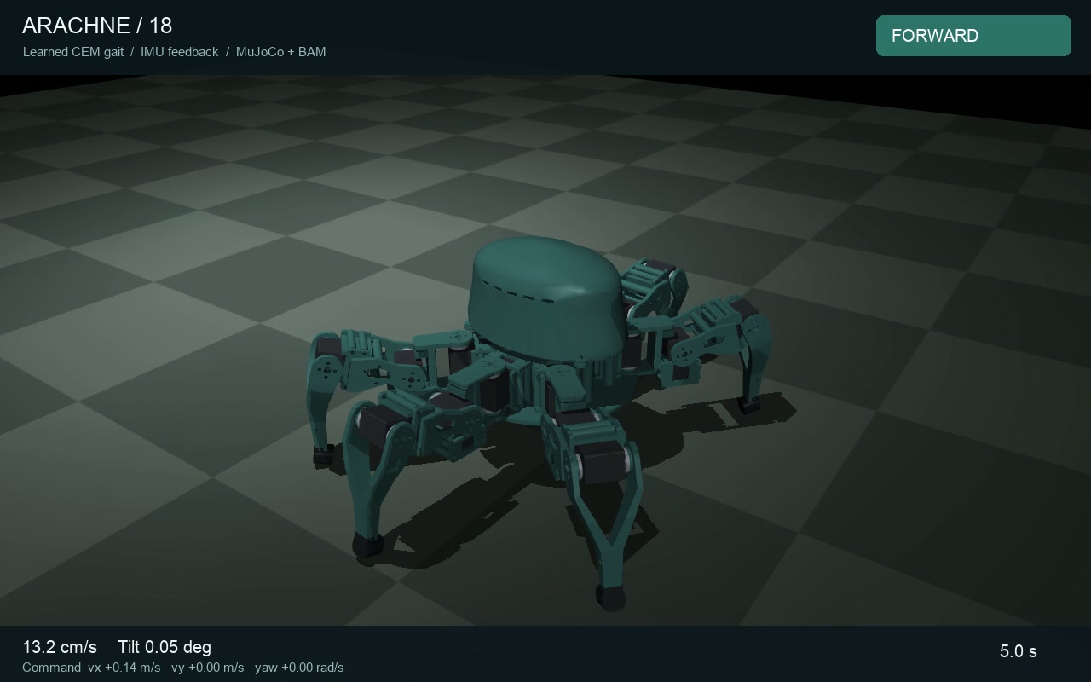
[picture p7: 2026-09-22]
assets/arachne-learned-omni.jpg

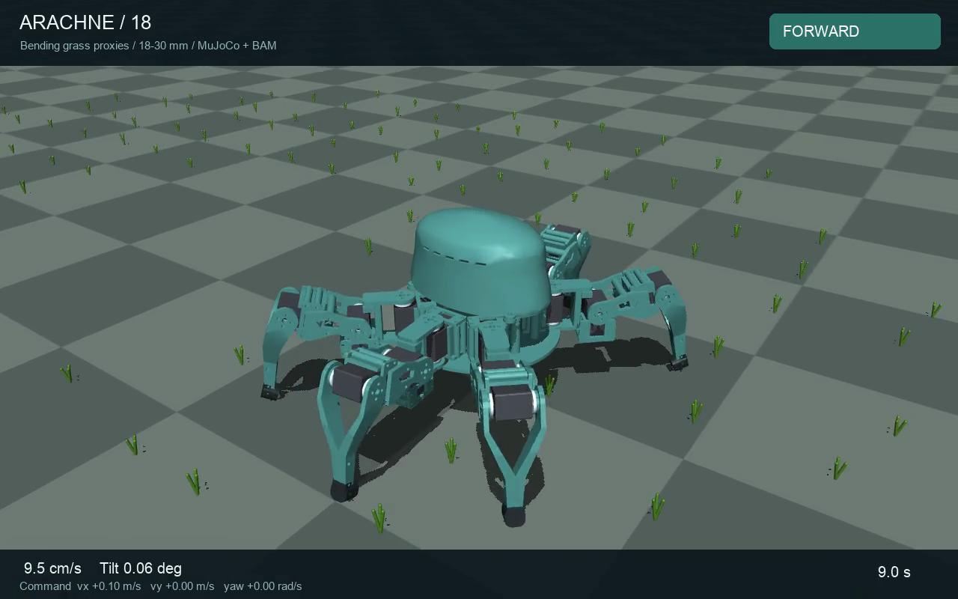
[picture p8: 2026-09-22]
assets/arachne-terrain-grass.jpg

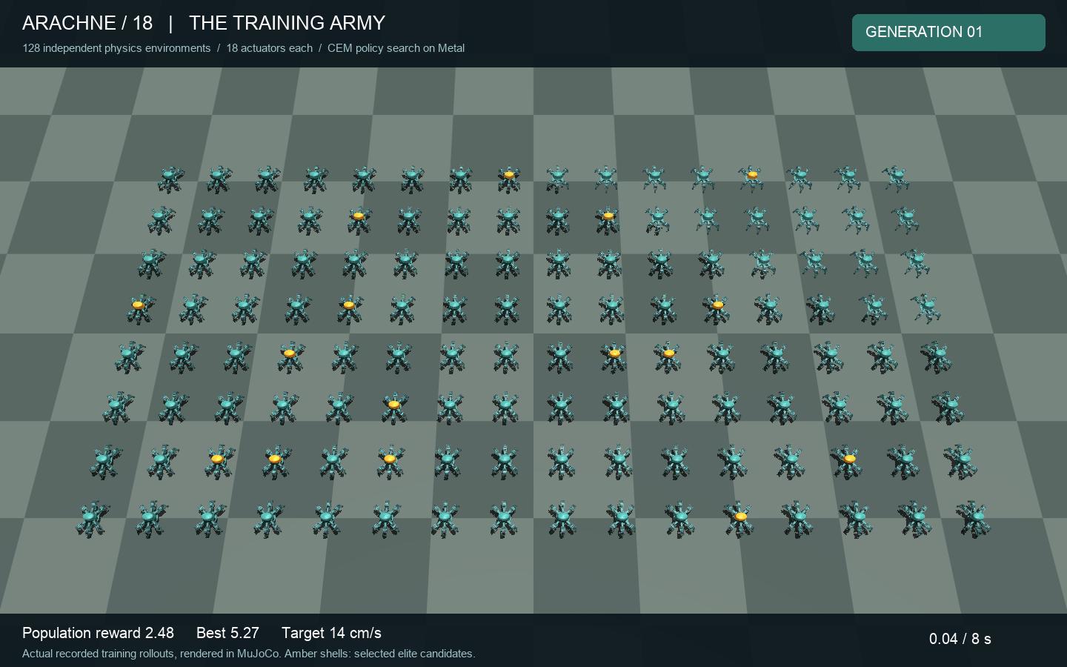
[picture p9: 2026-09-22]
assets/arachne-training-army.jpg

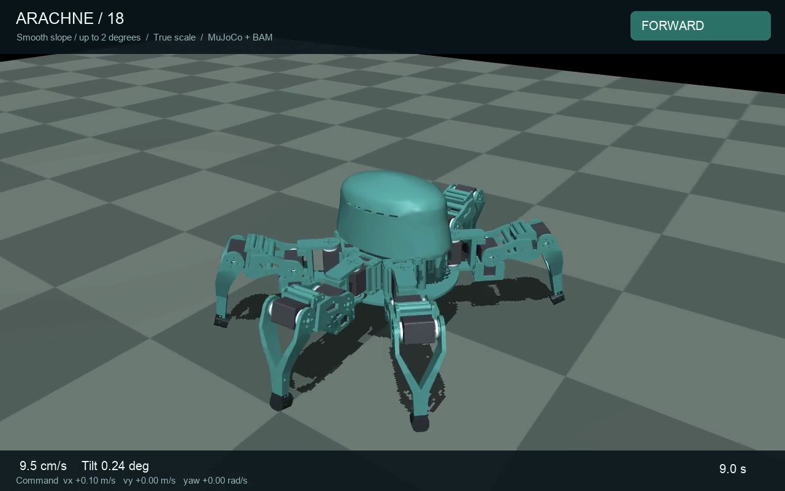
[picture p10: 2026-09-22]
assets/arachne-terrain-slope.jpg

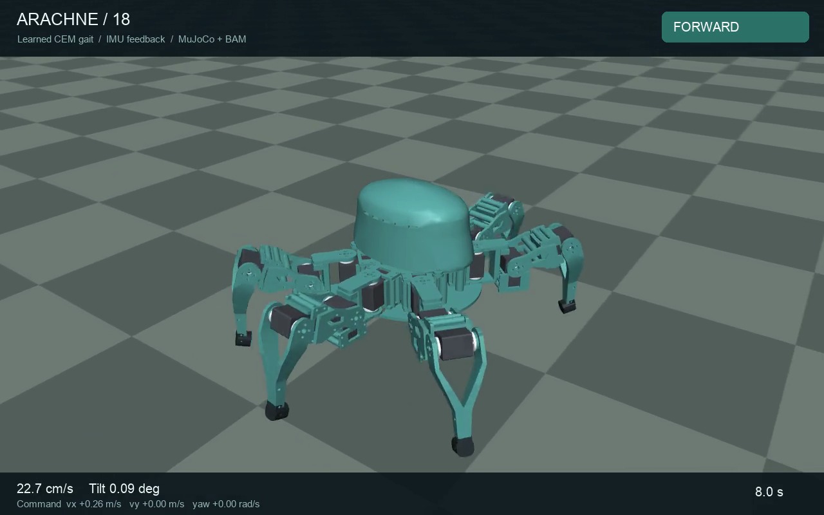
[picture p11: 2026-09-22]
assets/arachne-long-stride.jpg

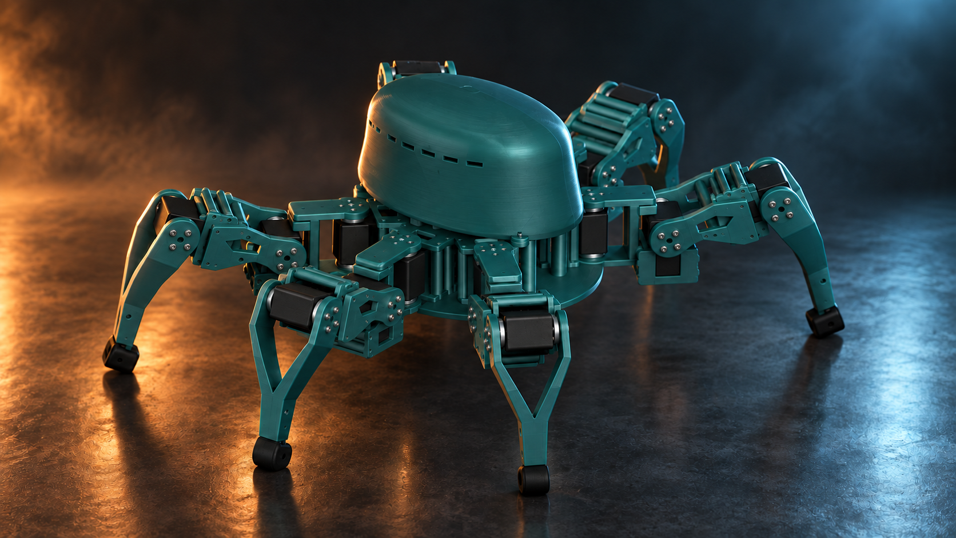
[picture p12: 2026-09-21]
assets/hero-studio.png

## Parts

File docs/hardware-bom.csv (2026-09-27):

item | quantity | location | notes
STS3215 12V servo | 18 | 3 per leg | Use the owner's 12V variant
Supplied driven metal horn | 18 | Inside each driven fork face | 2.5mm measured thickness
Supplied dummy metal horn | 18 | Inside each dummy fork face | 2.0mm measured thickness
DIN7380-1 M3x6 | 144 | Horn attachment | 4 screws per horn
DIN7380-1 M3x8 | 6 | TPU shoe to tibia | One per foot
DIN7380-1 M3x10 | 6 | 4 carrier and 2 canopy screws | 2mm hex drive
DIN7380-1 M3x12 | 4 | PCB and standoff to carrier | Assumes 1.6mm PCB and 6mm standoff
Supplied PA2 case screw | 72 | 4 per servo factory case mount | Reference assumes 5mm shank and 4mm head
Ruthex RX-M3x5.7 insert | 16 | 4 chassis 6 carrier 6 tibia | 4.0mm diameter x7mm pilot
Original horn retaining hardware | 18 sets | Servo center retainers | Reuse supplied hardware; not individually detailed in CAD
Battery retaining strap | 2 | Chassis slots | Choose width up to 14mm and length for actual pack
3S battery pack | 1 | Dorsal compartment | Nominal envelope115x40x35mm excluding plugs
Controller and power distribution | 1 set | Controller carrier | Nominal envelope90x60x18mm
Servo bus cables | As routed | Dummy-side ports | Verify plugs and leave flexible service loops

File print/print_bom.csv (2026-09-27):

part | quantity | material | size_X_mm | size_Y_mm | size_Z_mm
01_chassis | 1 | PLA/PETG | 194.0 | 173.47 | 55.95
02_controller_carrier | 1 | PLA/PETG | 147.0 | 78.0 | 48.0
03_organic_canopy | 1 | PLA/PETG | 184.07 | 116.1 | 90.64
04_coxa | 6 | PLA/PETG | 69.05 | 47.9 | 47.9
05_femur | 6 | PLA/PETG | 85.05 | 47.9 | 34.0
06_tibia | 6 | PLA/PETG | 129.13 | 47.9 | 32.17
07_tpu_shoe | 6 | TPU95A | 20.0 | 19.0 | 7.5
08_pcb_standoff | 4 | PLA/PETG | 9.0 | 9.0 | 6.0

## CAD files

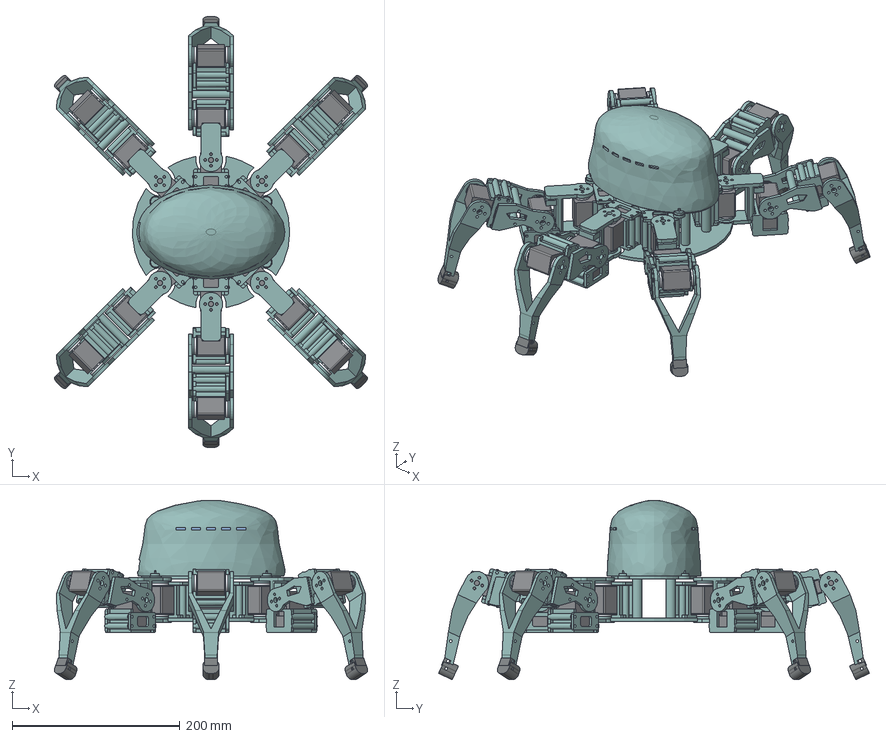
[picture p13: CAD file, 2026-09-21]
cad/ARACHNE_18_assembly.step
373.8 x 514.3 x 214.1 mm
01_CHASSIS
02_DORSAL_DECK
03_BATTERY_TRAY
04_CONTROLLER_PLATE
05_SHELL
REF_3S_BATTERY_115x40x35
REF_CONTROLLER_90x60x18
PCB_spacer_-32_-24
PCB_spacer_-32_24
PCB_spacer_32_-24
PCB_spacer_32_24
L1_S01_YAW_STS3215
L1_yaw_clamp
L1_coxa
L1_coxa_bottom
L1_S02_HIP_STS3215
L1_hip_clamp
L1_femur
L1_femur_side_plate
L1_S03_KNEE_STS3215
L1_knee_clamp
L1_tibia
L1_foot
L1_yaw_disc_plus
L1_yaw_disc_min
L1_yaw_shim_plus
L1_yaw_shim_min
L1_hip_disc_plus
L1_hip_disc_min
L1_hip_shim_plus
L1_hip_shim_min
L1_knee_disc_plus
L1_knee_disc_min
L1_knee_shim_plus
L1_knee_shim_min
L2_S04_YAW_STS3215
L2_yaw_clamp
L2_coxa
L2_coxa_bottom
L2_S05_HIP_STS3215
L2_hip_clamp
L2_femur
L2_femur_side_plate
L2_S06_KNEE_STS3215
L2_knee_clamp
L2_tibia
L2_foot
L2_yaw_disc_plus
L2_yaw_disc_min
L2_yaw_shim_plus
L2_yaw_shim_min
L2_hip_disc_plus
L2_hip_disc_min
L2_hip_shim_plus
L2_hip_shim_min
L2_knee_disc_plus
L2_knee_disc_min
L2_knee_shim_plus
L2_knee_shim_min
L3_S07_YAW_STS3215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

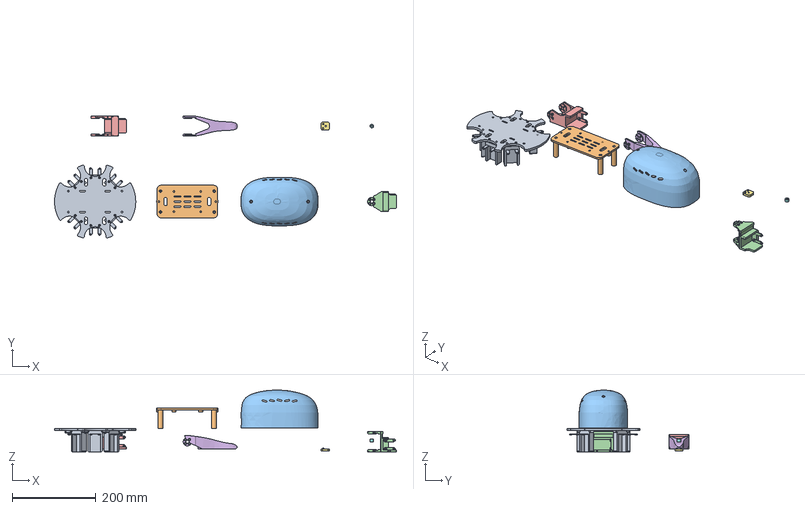
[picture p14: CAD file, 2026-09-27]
cad/ARACHNE_18_parts.step
816.0 x 290.7 x 146.9 mm
01_chassis
02_controller_carrier
03_organic_canopy
04_coxa
05_femur
06_tibia
07_tpu_shoe
08_pcb_standoff

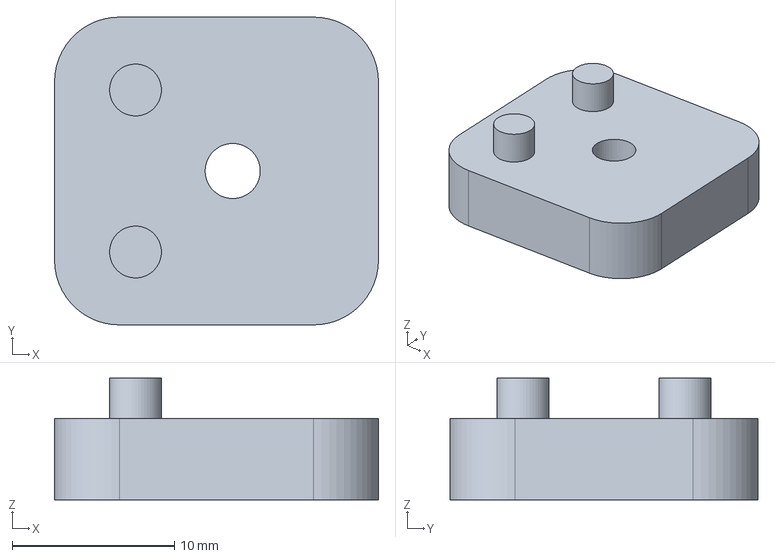
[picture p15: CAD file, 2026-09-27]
cad/parts/07_tpu_shoe.step
20.0 x 19.0 x 7.50 mm

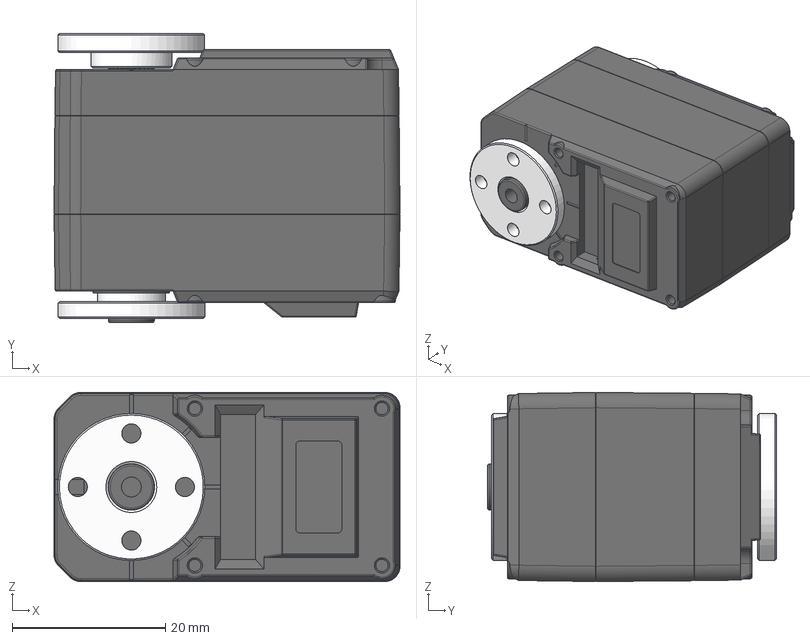
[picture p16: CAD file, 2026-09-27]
cad/reference/ST3215.step
45.2 x 37.8 x 24.7 mm
ZK_122
SG-ZIJI_15
XG-ZIJI_16
MOTOR-1723_3
PCB-CHAZUO_92
GE_27
金属舵盘（驱动）
金属舵盘（从动）

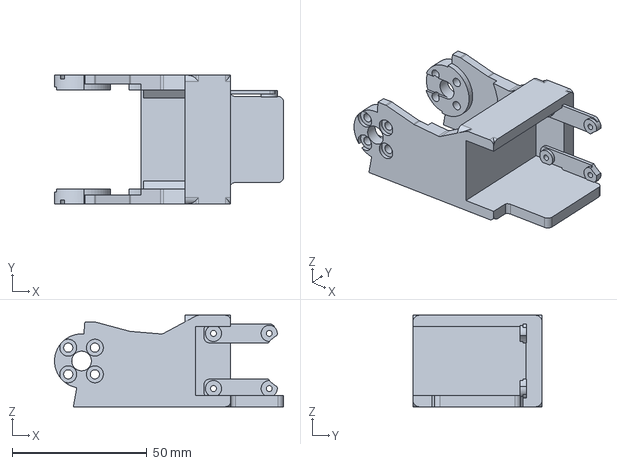
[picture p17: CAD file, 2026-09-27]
cad/reference/validated_v4/femur.step
85.0 x 47.9 x 34.0 mm

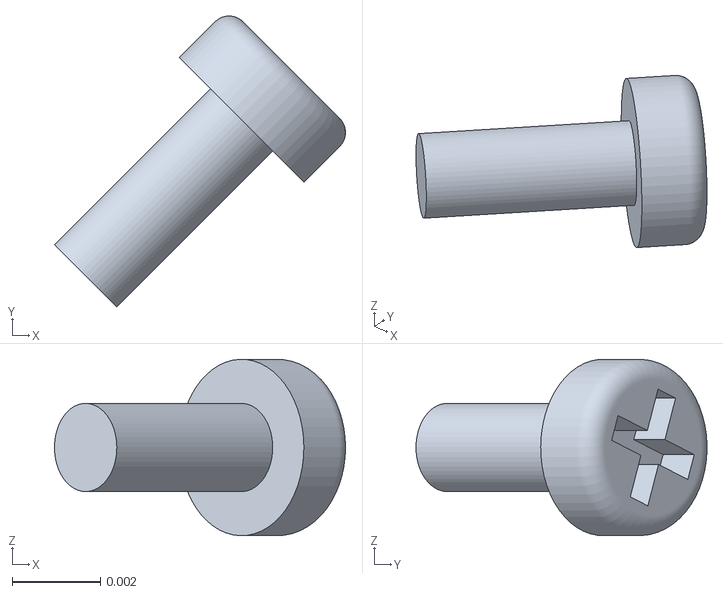
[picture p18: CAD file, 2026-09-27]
simulation/meshes/L6_knee_factory_PA2_-8.3_-10.25.stl
0.0066 x 0.0066 x 0.004

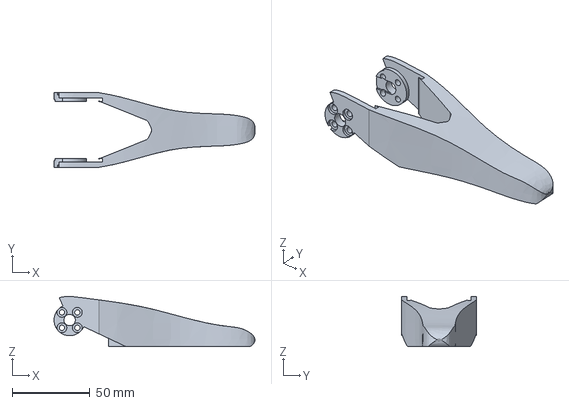
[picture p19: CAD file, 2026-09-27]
cad/reference/validated_v4/tibia.step
129.1 x 47.9 x 32.2 mm

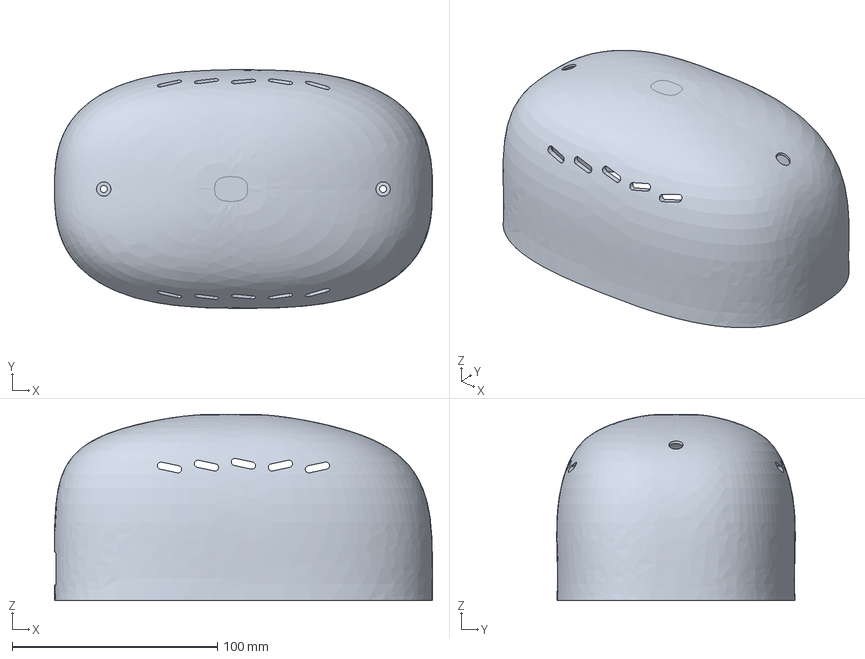
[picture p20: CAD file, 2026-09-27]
cad/parts/03_organic_canopy.step
184.0 x 116.2 x 90.6 mm

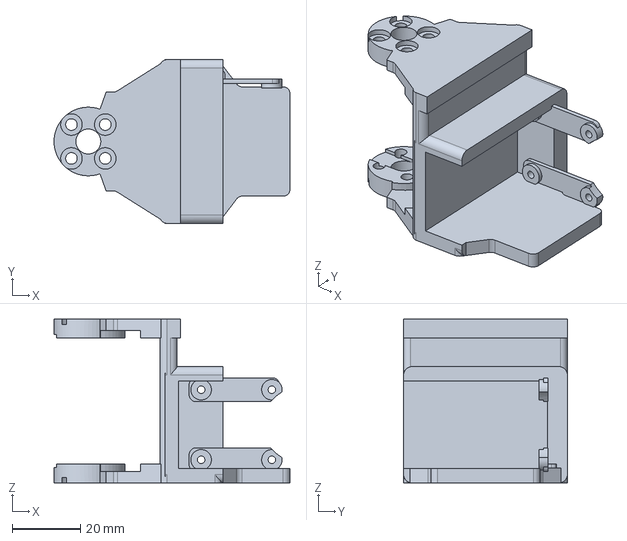
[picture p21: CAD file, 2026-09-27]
cad/reference/validated_v4/coxa.step
69.0 x 47.9 x 47.9 mm

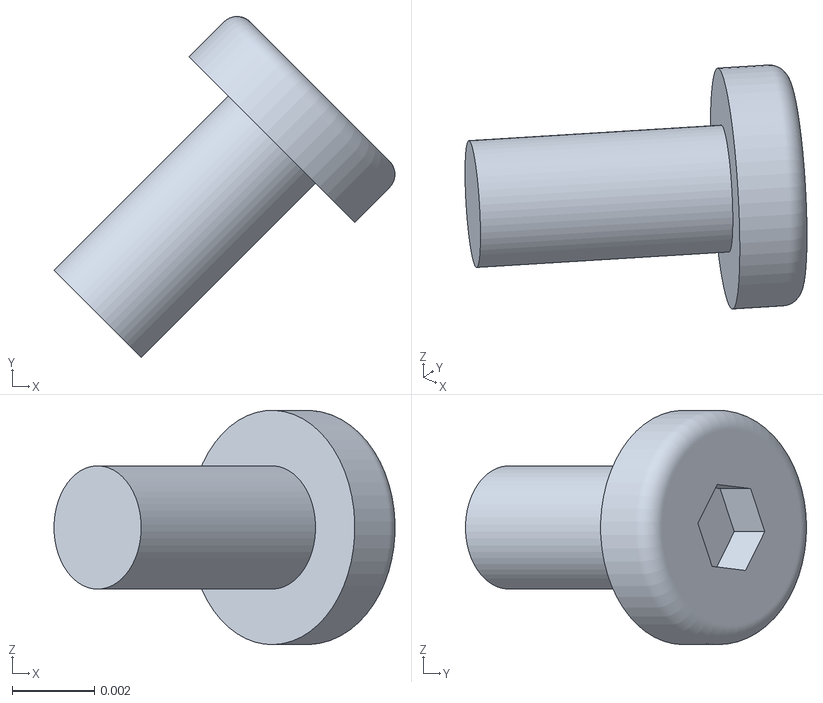
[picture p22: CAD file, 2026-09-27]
simulation/meshes/L3_knee_M3x6_-1_3.stl
0.0083 x 0.0083 x 0.0057

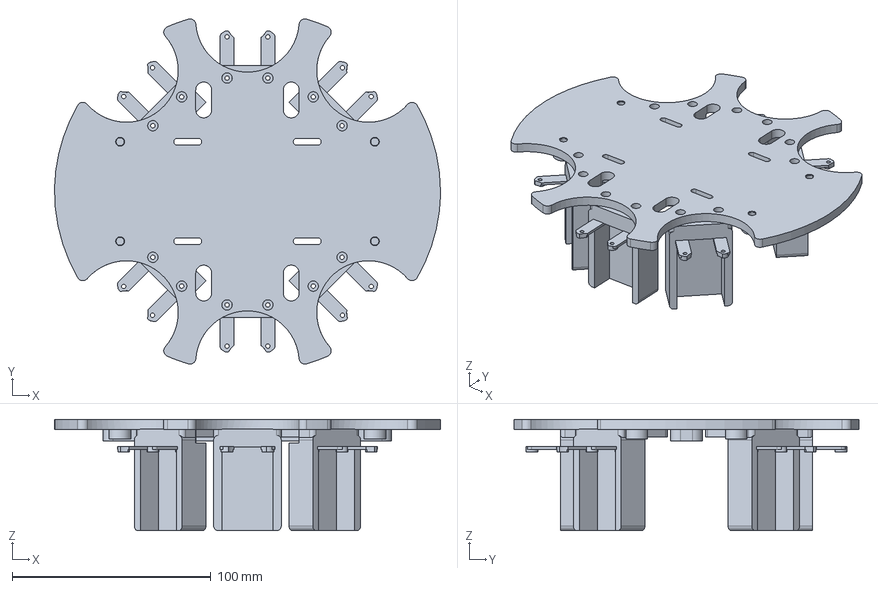
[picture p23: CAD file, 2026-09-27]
cad/parts/01_chassis.step
194.0 x 173.5 x 56.0 mm

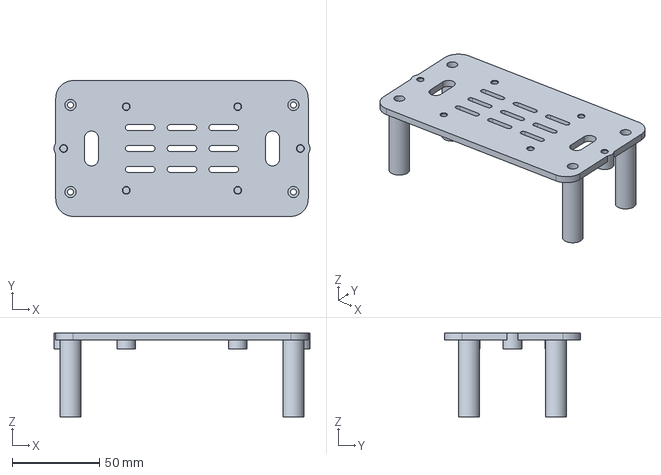
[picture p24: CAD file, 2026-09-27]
cad/parts/02_controller_carrier.step
147.0 x 78.0 x 48.0 mm

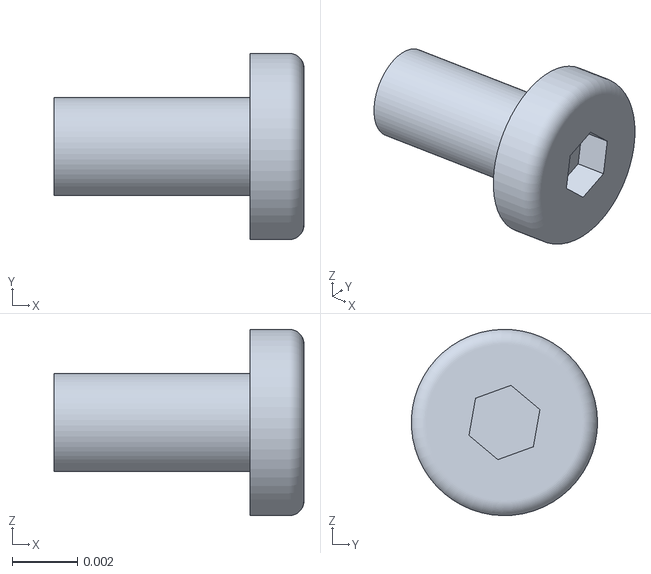
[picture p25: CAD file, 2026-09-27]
simulation/meshes/L2_hip_M3x6_-1_2.stl
0.00765 x 0.0057 x 0.0057

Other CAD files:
cad/parts/05_femur.step
simulation/meshes/L1_hip_factory_PA2_-8.3_-10.25.stl
cad/reference/validated_v4/shoe.step
simulation/meshes/L6_hip_factory_PA2_-29_-10.25.stl
cad/reference/validated_v4/chassis.step
cad/parts/04_coxa.step
cad/parts/06_tibia.step
cad/parts/08_pcb_standoff.step
print/stl/01_chassis.stl
print/stl/02_controller_carrier.stl
print/stl/03_organic_canopy.stl
print/stl/04_coxa.stl
print/stl/05_femur.stl
print/stl/06_tibia.stl
print/stl/07_tpu_shoe.stl
print/stl/08_pcb_standoff.stl
simulation/meshes/01_CHASSIS.stl
simulation/meshes/02_CONTROLLER_CARRIER.stl
simulation/meshes/05_SHELL.stl
simulation/meshes/BODY_PCB_M3x12_-32_-24.stl
simulation/meshes/BODY_PCB_M3x12_-32_24.stl
simulation/meshes/BODY_PCB_M3x12_32_-24.stl
simulation/meshes/BODY_PCB_M3x12_32_24.stl
simulation/meshes/BODY_PCB_insert_-32_-24.stl
simulation/meshes/BODY_PCB_insert_-32_24.stl
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

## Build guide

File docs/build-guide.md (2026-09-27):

# Building ARACHNE 18 v4

Use the current `print/stl/` files, not earlier revision downloads. Print one leg first. Fit depends on the actual servo, supplied horns, cables, filament shrinkage and printer calibration.

## Print plan

| Part | Quantity | Supplied orientation | Support |
|---|---:|---|---|
| 01_chassis | 1 | Flat dorsal deck on bed; cradles grow upward | Local cradle bridges |
| 02_controller_carrier | 1 | Flat top face on bed; four posts grow upward | Small local recesses |
| 03_organic_canopy | 1 | Open rim on bed | Internal roof and mounting tabs |
| 04_coxa | 6 | Continuous flat underside | Local fork bridge |
| 05_femur | 6 | Continuous flat underside | Local fork bridge |
| 06_tibia | 6 | Continuous flat underside | Local horn bridge |
| 07_tpu_shoe | 6 | Flat sole on bed | None in audit |
| 08_pcb_standoff | 4 | Flat annulus on bed | None in audit |

Use PLA for the first fit trial or a suitably calibrated tougher filament for later structural trials. The geometry audit used a 0.4 mm nozzle, 0.2 mm layers, five walls and 35% gyroid for rigid parts; TPU used 20% infill. Inspect bridge/support placement and layer preview on the H2D. Do not fill screw wells or narrow plug clearances with inaccessible support.

The canopy intentionally remains one removable piece. Its curved roof and internal tabs require support. The A1 proxy estimated about 87 g of canopy support; this is not a support-free part. The other unique rigid parts needed approximately 2–13 g each. These are rough support estimates; reslice on H2D for material and time estimates. No support/G-code settings are certified for a specific H2D material profile.

## Interfaces and screws

- Horn outer span: **36.5 mm** measured by the owner. Driven horn **2.5 mm**, dummy horn **2.0 mm**.
- Fork inside span: **36.9 mm**, providing 0.4 mm total fitting allowance. Both cheeks are **5.5 mm** thick.
- Horns mount **inside** the fork. Eight **DIN 7380 M3×6** screws per joint enter from outside: four per horn.
- Ø6.3 mm head recesses are 1.5 mm deep, leaving 4 mm beneath the head. A 6 mm screw crosses approximately 4.2 mm of cheek/clearance, leaving approximately 1.8 mm in the horn. Confirm engagement and bottoming on the actual horns before tightening.
- Ø7.3 mm center openings clear the measured Ø6.5 mm dummy shaft and allow access to the driven horn's original retaining screw. Shallow inner entry tracks let the shaft slide into the fork.
- Each servo case uses four factory mounting holes, **Ø2.2 mm** through holes and **Ø5.2 mm** head access. Use the supplied PA2 case screws, not M3 machine screws. The CAD assumes a 5 mm under-head length and Ø4 mm head; verify the supplied fasteners.
- Plastic M3 joints use **Ruthex RX-M3x5.7 inserts**. All pilots are **Ø4.0 × 7.0 mm**, with Ø4.5 entry relief. CAD inserts show the nominal installed envelope; thread/knurl detail is simplified.

| M3 joint | Screw | Printed stack to insert | Approx. insert engagement |
|---|---|---:|---:|
| Carrier → chassis | M3×10 | 4 mm | 6 mm to pilot; insert length 5.7 mm |
| Canopy → carrier | M3×10 | 4 mm | 6 mm to pilot; insert length 5.7 mm |
| PCB + standoff → carrier | M3×12 | 1.6 + 6 mm | 4.4 mm |
| TPU shoe → tibia | M3×8 | 2.6 mm | 5.4 mm |

The 7 mm pilot depth provides screw-tip clearance beyond the 5.7 mm insert. Screws must clamp the part before bottoming. Tighten plastic interfaces gently; load capacity has not been physically measured.

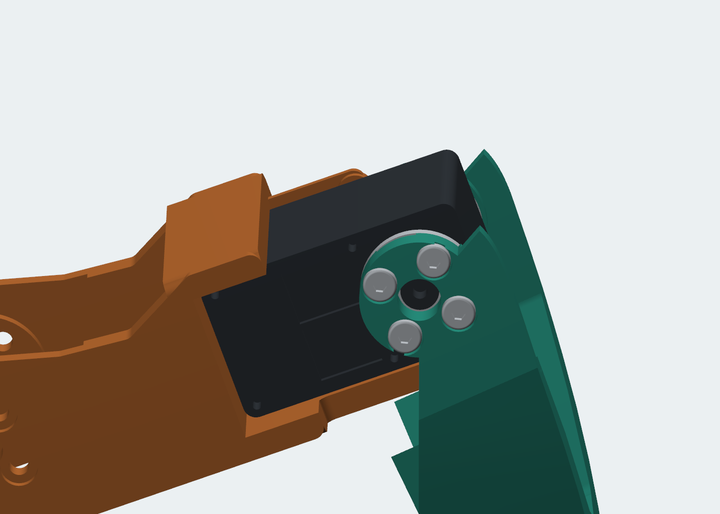
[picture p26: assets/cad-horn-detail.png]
V4 knee horn and recessed outside screws


## Assemble one leg

1. Remove support and check the flat surfaces, all four holes at every horn and the center shaft opening. Test the real servo and both horns before installing inserts or printing the remaining legs.
2. Remove the horns, slide the hip servo into the coxa cradle from the open dummy side and fasten the driven-side factory case holes with four supplied PA2 screws. Install the knee servo in the femur similarly.
3. Connect/route the bus cables on the **dummy side** while they remain accessible. Leave a service loop at every moving joint. The checked plug/straight-exit envelope is estimated; it is not a model of flexible cable motion.
4. Fit and center the supplied horns on each servo. Slide the femur fork onto the hip horn pair, and the tibia fork onto the knee horn pair, using the shallow dummy-shaft entry track. Fit the recessed M3×6 horn screws from outside. Access the central horn retainer through the center opening.
5. Heat-set one M3 insert into the tibia shoe pilot. Fit the TPU shoe and its M3×8 screw.
6. Sweep the leg slowly by hand/power-limited motion. Check cable bend radii, case screw heads, horn retainers and plugs throughout the intended range. Do not force motion against printed parts or cable tension.

The three structural moving links are monolithic. No side-plate joining screws or structural shims are needed. The tibia is symmetric; only functional dummy-side entry/connector details make the other links locally asymmetric.

## Chassis and dorsal compartment

1. Fit four inserts in the chassis at X=±64, Y=±25 mm. Fit six inserts in the carrier: four PCB positions at X=±32, Y=±24, and two cover positions at X=±68, Y=0.
2. Insert the six yaw servos into the chassis from below with horns removed. Secure each with four supplied case screws. The dummy face and its connectors face down. Attach the coxa forks to the horn pairs using the same M3×6 interfaces as the other joints.
3. Run two battery straps through the 14×3.5 mm slots at X=±30, Y=±25. The underside route is clear at Z≈20 mm. Fit a protective pad and the battery; allow additional room for leads and connector strain relief.
4. Lower the carrier onto the four chassis bosses. Install four M3×10 screws through its open access wells using a slim **2 mm hex driver** with at least 50 mm usable reach. The screw heads seat near the bottoms of the wells.
5. Install the controller using four 6 mm standoffs and M3×12 screws. The reference PCB is 90×60×1.6 mm with 64×48 mm mounting pitch. Adapt `PCB_MOUNTS` in `src/v4_dorsal.py` to the actual board before printing. Extra slots support alternative mounting arrangements; check that they clear components and underside solder joints.
6. Route leads through the carrier slots and rear canopy opening. Lower the canopy and fasten its two M3×10 screws through the top driver openings. The canopy can be removed without disturbing the legs or carrier.

Battery space is 115×40×35 mm and controller space is 90×60×18 mm. These are nominal envelopes, not endorsements of a specific pack/board. The intended source is a 3S battery (11.1 V nominal, 12.6 V full) for the 12 V servo variant. Power distribution, fuse, connector current rating and logic-voltage regulation remain controller/pack-specific electrical design work.

## Commissioning

Assign IDs 1–18 using `simulation/joint_map.json`, verify each servo's sign and center, and start with one unloaded leg at limited speed/current. CAD joint ranges are geometric limits, not verified hardware travel. Stand tests use much smaller motion. Confirm physical fit, rigidity, insert retention and cable clearance before attempting load-bearing walking.

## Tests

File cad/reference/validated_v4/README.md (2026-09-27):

# Frozen v4 component baseline

These five solids are the previously checked isolated leg/body prototypes, before full-robot integration. `check_v4.py` checks their equivalence to the current build. STEP comparison ignores only generated product labels and timestamps; remaining differences use a geometric subtraction check.

The corresponding fit reports retain the original file hashes. `../ST3215.step` is the manufacturer reference used for case, fastener and insertion checks. The assembled visual servo is a simplified valid exterior model in `src/v4_servo.py`: the vendor STEP includes an invalid internal solid and is not used as the native assembly part.

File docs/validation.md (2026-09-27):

# V4 validation record

These checks establish consistency of the digital prototype. They do not certify physical fit, load capacity or hardware performance.

| Check | Result / scope | Evidence |
|---|---|---|
| Print solids | 8/8 valid, one solid each | [CAD report](../validation/cad_validation.json) |
| Print meshes | 8/8 watertight, one component; flat bed contact | [Integration report](../validation/integration_v4.json) |
| Baseline geometry | Chassis and four leg parts match the checked v4 prototypes | [Integration report](../validation/integration_v4.json) |
| Packaging | Battery, PCB, controller envelope, carrier and canopy clearance | [Integration report](../validation/integration_v4.json) |
| Screw/print fit | 160 M3 and 72 factory screws; no print overlap above 0.05 mm³ | [Integration report](../validation/integration_v4.json) |
| Dorsal tool access | Carrier, PCB and cover driver paths clear in assembly order | [Integration report](../validation/integration_v4.json) |
| Leg interfaces | Case insertion, horns, screw bearing, head access, dummy plugs and sampled joint sweeps | [Leg report](../validation/leg_v4.json) |
| Chassis interfaces | Six case insertion paths and plug service columns; factory and horn tool access | [Body report](../validation/body_fit_v4.json) |
| Chassis motion | 90 combined representative poses, yaw sweep, neutral leg pairs | [Body report](../validation/body_fit_v4.json) |
| Paired toe reach | Front and rear, 13 coordinated samples per path; shoes meet | [Body report](../validation/body_fit_v4.json) |
| Dorsal motion | 162 sampled leg poses against carrier and canopy | [Integration report](../validation/integration_v4.json) |
| Installation | Fork insertion, case-head clearance and battery-strap corridors | [Installation report](../validation/body_mount_sequence_v4.json) |
| Slicing | 8 parts sliced without reported warnings; A1 geometry proxy, not H2D G-code | [Slicer report](../validation/slicer_v4.json) |
| Onshape native graph | 336 instances, 317 fastened, 18 revolute; fixed chassis | [Native report](../simulation/onshape_validation.json) |
| Onshape limits | All 18 native limits match joint map | [Limit report](../simulation/onshape_motion_validation.json) |
| MuJoCo | 19 links, 18 hinges; positive inertias, correct subtrees, reproducible reset | [Simulation report](../simulation/simulation_validation.json) |
| Standing | 10 seconds each at 11.1/12.0/12.6 V; all six feet support the body | [Simulation report](../simulation/simulation_validation.json) |
| Fixed sweep | 12 seconds; tracking error below 0.73° after settling | [Simulation report](../simulation/simulation_validation.json) |
| Grounded exercise | 8 seconds; six supporting feet, 12 contact points; no warnings | [Grounded report](../simulation/grounded_validation.json) |
| Animation | 100 frames / 4 seconds; six feet support the free base | [Animation report](../validation/grounded_animation.json) |
| Training compatibility | 17 existing unit tests pass; no training performed | [Compatibility report](../validation/training_compatibility_v4.json) |

The leg horn-bearing test samples material under all four screws on both faces of every joint type. The chassis and leg source tests use the vendor case reference plus the owner's measured Ø6.5 mm dummy shaft. Connector checks use an estimated two-plug and straight-exit envelope on the dummy side. Flexible wire movement and real plug dimensions still need a physical trial.

Motion checks are discrete samples and selected installation paths. They are not exhaustive continuous collision proofs across all 18 joint combinations. The current simulation uses approximate collision shapes and nominal mass distributions; standing does not validate walking, jumping, thermal limits or structural strength.

No physical print, pull-out test, FEA, fatigue or impact test has been completed. Existing RL metrics and videos belong to earlier geometry. Historical v3 evidence is isolated under `validation/legacy-v3/` and is not used to claim current performance.

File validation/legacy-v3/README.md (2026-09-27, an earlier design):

# Archived v3 evidence

These reports describe the pre-v4 geometry. Current evidence is in the parent directory and simulation/. They do not validate v4. The previous CAD and training model can be restored from Git commit `9a6ca7c`.

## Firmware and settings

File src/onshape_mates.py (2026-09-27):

"""Apply the reviewable ARACHNE mate plan via the official Onshape REST API.

Credentials are read from a separate mode-0600 JSON, never printed or exported.
Only operates on the document/workspace/assembly in onshape_mate_plan.json.
"""
from pathlib import Path
import json, argparse, copy, math, time, secrets, email.utils, hmac, hashlib, base64
import urllib.request, urllib.parse, urllib.error
import numpy as np

ROOT=Path(__file__).resolve().parent.parent
OUT=ROOT/'simulation'
WORK=ROOT/'build/onshape';WORK.mkdir(parents=True,exist_ok=True)
NAME_MAP=json.loads((ROOT/'cad/onshape_name_map.json').read_text())
def native_names(obj):
    if isinstance(obj,dict):return {native_names(k):native_names(v) for k,v in obj.items()}
    if isinstance(obj,list):return [native_names(v) for v in obj]
    if isinstance(obj,str):
        if obj in NAME_MAP:return NAME_MAP[obj]
        for prefix in ('MC_','F_'):
            if obj.startswith(prefix) and obj[len(prefix):] in NAME_MAP:
                return prefix+NAME_MAP[obj[len(prefix):]]
    return obj
PLAN=native_names(json.loads((OUT/'onshape_mate_plan.json').read_text()))
META=native_names(json.loads((OUT/'cad_instances.json').read_text()))
LINKS=native_names(json.loads((OUT/'mass_properties.json').read_text()))['links']
PREFIX=f"/api/v17/assemblies/d/{PLAN['documentId']}/w/{PLAN['workspaceId']}/e/{PLAN['elementId']}"

class Client:
    def __init__(self,keyfile):
        self.keys=json.loads(Path(keyfile).read_text())
    def call(self,method,suffix='',body=None,query=None):
        path=PREFIX+suffix;qs=urllib.parse.urlencode(query or {})
        url='https://cad.onshape.com'+path+('?' + qs if qs else '')
        nonce=secrets.token_hex(16);date=email.utils.formatdate(usegmt=True);ctype='application/json'
        sign='\n'.join([method,nonce,date,ctype,path,qs,'']).lower()
        mac=base64.b64encode(hmac.new(self.keys['secretKey'].encode(),sign.encode(),hashlib.sha256).digest()).decode()
        headers={'Date':date,'On-Nonce':nonce,'Content-Type':ctype,'Accept':'application/json',
                 'Authorization':f"On {self.keys['accessKey']}:HmacSHA256:{mac}"}
        req=urllib.request.Request(url,headers=headers,method=method,data=None if body is None else json.dumps(body).encode())
        try:
            with urllib.request.urlopen(req,timeout=90) as resp:
                raw=resp.read();return json.loads(raw) if raw else {}
        except urllib.error.HTTPError as e:
            raise RuntimeError(f'Onshape HTTP {e.code}: '+e.read().decode()[:1500]) from None

def enum(pid,value,name):return dict(btType='BTMParameterEnum-145',parameterId=pid,enumName=name,value=value)
def boolean(pid,value):return dict(btType='BTMParameterBoolean-144',parameterId=pid,value=value)
def quantity(pid,value,unit='m'):return dict(btType='BTMParameterQuantity-147',parameterId=pid,expression=f'{value:.12g} {unit}',isInteger=False)
def query(pid,queries):return dict(btType='BTMParameterQueryWithOccurrenceList-67',parameterId=pid,queries=queries)
def feature_query(fid):return dict(btType='BTMFeatureQueryWithOccurrence-157',path=[],featureId=fid,queryData='')
def origin_query(instance):return dict(btType='BTMInferenceQueryWithOccurrence-1083',inferenceType='PART_ORIGIN',path=[instance],deterministicIds=[''])

def connector(name,source,position=(0,0,0),rotation=0,rotation_axis='ABOUT_Z'):
    return dict(btType='BTMMateConnector-66',featureType='mateConnector',name=name,implicit=False,isHidden=True,
        suppressed=False,parameters=[enum('originType','ON_ENTITY','Origin type'),query('originQuery',[source]),
        query('originAdditionalQuery',[]),boolean('realign',False),query('primaryAxisQuery',[]),query('secondaryAxisQuery',[]),
        boolean('transform',True),*[quantity('translation'+k,v) for k,v in zip('XYZ',position)],
        enum('rotationType',rotation_axis,'Rotation axis'),quantity('rotation',rotation,'deg'),
        boolean('flipPrimary',False),enum('secondaryAxisType','PLUS_X','Reorient secondary axis')])

def mate(name,kind,first,second,limits=None):
    params=[enum('mateType',kind,'Mate type'),query('mateConnectorsQuery',[feature_query(first),feature_query(second)])]
    if limits:
        params.append(boolean('limitsEnabled',True))
        for pid,val in zip(['limitAxialZMin','limitAxialZMax'],limits):
            params.append(dict(btType='BTMParameterNullableQuantity-807',parameterId=pid,isInteger=False,isNull=False,expression=f'{val} deg'))
    return dict(btType='BTMMate-64',featureType='mate',name=name,suppressed=False,parameters=params)

def group_angle(group):return 0 if group=='BODY' else [45,90,135,225,270,315][int(group[1])-1]

class Installer:
    def __init__(self,client,limit=0):
        self.client=client;self.limit=limit;self.count=0
        self.snapshot=client.call('GET','/features')
        self.features={f['name']:f for f in self.snapshot['features']}
        self.states=self.snapshot['featureStates']
        self.log=[]
    def ensure(self,feature):
        name=feature['name']
        if name in self.features:
            f=self.features[name]
            state=self.states.get(f['featureId'],{})
            if state.get('featureStatus')!='OK':raise RuntimeError(f'Existing feature {name} is not OK: {state}')
            return f['featureId']
        if self.limit and self.count>=self.limit:raise StopIteration('Action limit reached; safely resumable')
        result=self.client.call('POST','/features',{'feature':feature})
        self.count+=1
        f=result['feature']; state=result['featureState'];self.features[name]=f;self.states[f['featureId']]=state
        record=dict(name=name,id=f['featureId'],status=state['featureStatus']);self.log.append(record)
        with (WORK/'install_log.jsonl').open('a') as stream:stream.write(json.dumps(record)+'\n')
        print(self.count,name,state['featureStatus'],flush=True)
        if state['featureStatus']!='OK':raise RuntimeError(f'Onshape failed to solve {name}')
        return f['featureId']
    def apply(self,stage='all'):
        # This is the one deliberately incomplete probe made during schema discovery.
        probe=self.features.get('F_BODY_02_RUGPLATFORM')
        if probe and probe['featureId']=='MwT6qk9xacQ5dpvLB' and self.states.get(probe['featureId'],{}).get('featureStatus')=='ERROR':
            self.client.call('DELETE','/features/featureid/'+urllib.parse.quote(probe['featureId'],safe=''))
            del self.features[probe['name']]
        mc={}
        for o in META:
            group=o['group'];n=o['name']
            mc[n]=self.ensure(connector('MC_'+n,origin_query(PLAN['instances'][n]['id']),LINKS[group]['origin_neutral_m'],group_angle(group)))
        if stage=='connectors':return
        for m in PLAN['fastened']:self.ensure(mate(m['name'],'FASTENED',mc[m['parent']],mc[m['child']]))
        if stage=='fastened':return
        for m in PLAN['revolute']:
            leg=int(m['name'][3]);kind=m['name'].split('_')[-1];angle=[45,90,135,225,270,315][leg-1]
            if kind=='yaw':
                parent_mc=self.ensure(connector('J_'+m['name']+'_parent',origin_query(PLAN['instances'][m['parent']]['id']),m['origin_m'],angle))
                child_mc=mc[m['child']]
            else:
                distance=[.062,0,-.00695] if kind=='hip' else [.078*math.cos(math.radians(20)),0,.078*math.sin(math.radians(20))]
                parent_mc=self.ensure(connector('J_'+m['name']+'_parent',feature_query(mc[m['parent']]),distance,90,'ABOUT_X'))
                child_mc=self.ensure(connector('J_'+m['name']+'_child',feature_query(mc[m['child']]),[0,0,0],90,'ABOUT_X'))
            self.ensure(mate(m['name'],'REVOLUTE',parent_mc,child_mc,m['range_delta_deg']))
    def verify(self):
        f=self.client.call('GET','/features');a=self.client.call('GET',query={'includeMateFeatures':'true','includeMateConnectors':'true'})
        (WORK/'features_after.json').write_text(json.dumps(f,indent=2))
        (WORK/'assembly_after.json').write_text(json.dumps(a,indent=2))
        mates=[x for x in f['features'] if x['featureType']=='mate']
        types=[next(p['value'] for p in x['parameters'] if p['parameterId']=='mateType') for x in mates]
        errors={fid:s for fid,s in f['featureStates'].items() if s.get('featureStatus')!='OK'}
        occ=a['rootAssembly']['occurrences'];base_id=PLAN['instances']['01_CHASSIS']['id']
        fixed=[o['path'] for o in occ if o.get('fixed')]
        drift=max(np.max(np.abs(np.array(o['transform']).reshape(4,4)-np.eye(4))) for o in occ)
        report=dict(fastened=types.count('FASTENED'),revolute=types.count('REVOLUTE'),errors=errors,fixed=fixed,
            max_neutral_transform_deviation=float(drift),instances=len(a['rootAssembly']['instances']),
            document_url=f"https://cad.onshape.com/documents/{PLAN['documentId']}/w/{PLAN['workspaceId']}/e/{PLAN['elementId']}")
        (OUT/'onshape_validation.json').write_text(json.dumps(report,indent=2));print(json.dumps(report,indent=2))
        assert types.count('FASTENED')==len(META)-len(LINKS) and types.count('REVOLUTE')==18
        assert len(a['rootAssembly']['instances'])==len(META)
        assert not errors and [base_id] in fixed and drift<1e-6

if __name__=='__main__':
    p=argparse.ArgumentParser(description=__doc__);p.add_argument('--key-file',type=Path,required=True)
    p.add_argument('--limit',type=int,default=0);p.add_argument('--stage',choices=['connectors','fastened','all','verify'],default='all')
    args=p.parse_args();installer=Installer(Client(args.key_file),args.limit)
    try:
        if args.stage!='verify':installer.apply(args.stage)
        if args.stage in ['all','verify']:installer.verify()
    except StopIteration as e:print(e)

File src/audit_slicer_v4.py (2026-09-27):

"""Bambu Studio geometry audit using its single-extruder A1 0.4 mm profile.

This avoids H2D headless extruder-mapping errors. It is a support/geometry
proxy, NOT H2D G-code. Use the H2D profile for the physical print.
"""
from pathlib import Path
import subprocess
import json
import re
import hashlib

HERE=Path(__file__).resolve().parent.parent/'build/v4'
ROOT=Path('/Applications/BambuStudio.app/Contents/Resources/profiles/BBL')
APP='/Applications/BambuStudio.app/Contents/MacOS/BambuStudio'
def resolved(path,category):
    data=json.loads(path.read_text());result={}
    if data.get('inherits'):result.update(resolved(ROOT/category/(data['inherits']+'.json'),category))
    for inc in data.get('include',[]):result.update(resolved(ROOT/category/(inc+'.json'),category))
    result.update({k:v for k,v in data.items() if k not in ('inherits','include')})
    return result
report={"slicer":"Bambu Studio 02.08.02.61","printer_profile":"A1 0.4 mm — geometry proxy only",
        "target_printer":"Bambu H2D; reslice before printing","layer_height_mm":.2,
        "walls":5,"infill":"35% gyroid","parts":{}}
for stl in sorted((HERE/'STL').glob('0*.stl')):
    out=Path('/tmp/arachne-release-v4-slicer')/stl.stem;out.mkdir(parents=True,exist_ok=True)
    profile=resolved(Path(__file__).resolve().parent/'v4_slicer_profile.json','process')
    if 'tpu' in stl.stem:profile.update(enable_support='0',sparse_infill_density='20%')
    (out/'process.json').write_text(json.dumps(profile))
    filament='Generic TPU @BBL A1.json' if 'tpu' in stl.stem else 'Generic PLA @BBL A1.json'
    (out/'machine.json').write_text(json.dumps(resolved(ROOT/'machine/Bambu Lab A1 0.4 nozzle.json','machine')))
    (out/'filament.json').write_text(json.dumps(resolved(ROOT/'filament'/filament,'filament')))
    cmd=[APP,'--slice','0','--orient','0','--arrange','1','--load-settings',
         str(out/'machine.json')+';'+str(out/'process.json'),
         '--load-filaments',str(out/'filament.json'),'--outputdir',str(out),str(stl)]
    run=subprocess.run(cmd,stdout=subprocess.PIPE,stderr=subprocess.STDOUT,text=True)
    (out/'log.txt').write_text(run.stdout)
    result=json.loads((out/'result.json').read_text())
    if run.returncode or result.get('return_code',0):raise RuntimeError(result)
    plates=result.get('sliced_plates',[])
    feature='';support_e=0.;total_e=0.
    for gcode in out.glob('*.gcode'):
        for line in gcode.read_text().splitlines():
            if line.startswith('; FEATURE: '):feature=line[11:]
            if line.startswith(('G0 ','G1 ')):
                m=re.search(r'(?:^| )E(-?(?:\d+(?:\.\d*)?|\.\d+))',line)
                if m and float(m[1])>0:
                    total_e+=float(m[1])
                    if feature.startswith('Support'):support_e+=float(m[1])
    report['parts'][stl.stem]={"sha256":hashlib.sha256(stl.read_bytes()).hexdigest(),
         "warning_message":[w for p in plates for w in p.get('warning_message',[])],
         "support_g_approx":round(support_e*.00298,2),"total_extrusion_g_approx":round(total_e*.00298,2),
         "material":"TPU" if 'tpu' in stl.stem else "PLA", "raw_result":result}
    print(stl.stem,report['parts'][stl.stem]['support_g_approx'],report['parts'][stl.stem]['warning_message'],flush=True)
(HERE/'slicer_audit.json').write_text(json.dumps(report,indent=2)+'\n')

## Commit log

2026-09-21 Add printable ARACHNE hexapod CAD and BAM-driven MuJoCo model
    [01_CHASSIS.stl, 01_chassis.step, 01_chassis.stl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]
2026-09-22 Train smooth IMU-aware locomotion and publish solo and training-army videos
2026-09-22 Rebuild symmetric hexapod legs with supported horn eyes
    [01_CHASSIS.stl, 01_chassis.step, 01_chassis.stl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]
2026-09-22 Verify complete Onshape mate graph and joint limits
2026-09-27 Integrate complete v4 robot, native Onshape mates and MuJoCo model
    [01_CHASSIS.stl, 01_chassis.step, 01_chassis.stl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]
